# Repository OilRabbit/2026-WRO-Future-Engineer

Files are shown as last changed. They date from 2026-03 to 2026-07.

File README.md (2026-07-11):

# Welcome to the GitHub Repository of Team Evo1ution for 2026 WRO Future Engineering 

## Links

[About Our Team](#about-our-team)

[Documentation](https://github.com/OilRabbit/2026-WRO-Future-Engineer/blob/Gen-1.0/Documentation/2026WROFEReport.pdf)

[Vehicle photos](vehicle_photos)

[Practice Videos](https://github.com/OilRabbit/2026-WRO-Future-Engineer/tree/Gen-1.0/video/video.md)

[Our Code](https://github.com/OilRabbit/2026-WRO-Future-Engineer/tree/Gen-1.0/src)

[Wiring Diagram](https://github.com/OilRabbit/2026-WRO-Future-Engineer/blob/Gen-1.0/schemes/Kicad/gen1_wiringdiagram.pdf)

[Building Instructions](https://github.com/OilRabbit/2026-WRO-Future-Engineer/blob/Gen-1.0/Documentation/FE%20building%20instructions.pdf)

## About Our Team

Our team consists of seven alumni from Po Leung Kuk Tang Yuk Tien College, each of whom previously served as chairperson of the school’s Robotics Team or has a strong interest in robotics. Over years of competitions and training, we have built strong friendships and developed a shared commitment to robotics. Last year, our team participated in the WRO Singapore final and placed 28th. Although we want to achieve higher this year, two of our teammates cannot participate due to academic reasons. Thus, we have two new teammates this year, Harrison and Donald become part of our supporters this year.

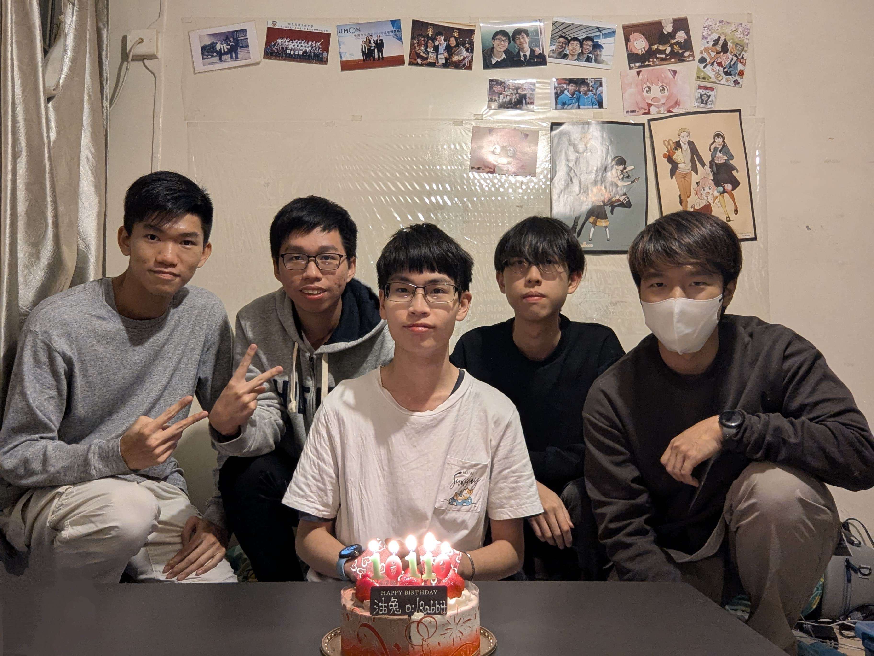
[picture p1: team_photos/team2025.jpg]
team_photo

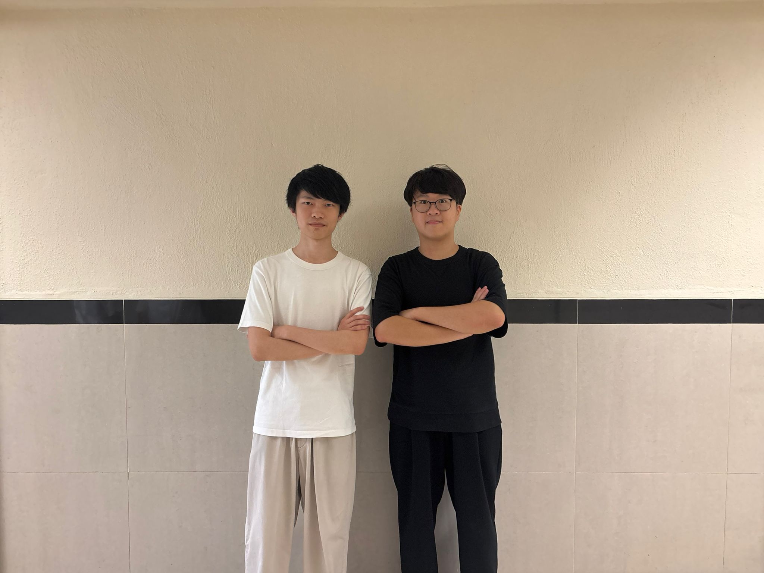
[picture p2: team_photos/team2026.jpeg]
team_photo

### Members' Introductions

#### Kyle Cheung (Participant) – Age 18
Kyle, a secondary school graduate, is responsible for program development in the PLKTYTC Robotics Team. He achieved first and second place in the 2023 and 2024 WRO Hong Kong RoboSports category. While preparing for the 2026 Robocon Hong Kong Contest, he draws on his strong competition background.

#### Marco Lam (Participant) – Age 19
Marco, an Enrichment Stream in Theoretical Physics student at The Chinese University of Hong Kong, is responsible for developing the main program, conducting module tests, and fine-tuning robot performance across diverse sce-narios. Although this is his first robotics competition since primary school, his strong foundation in programming — highlighted by achieving Honourable Mention in the Hong Kong Olympiad in Informatics (2022–
2023) — has proven valuable to the team. 

#### Rex Sin (Participant) – Age 20
Rex is studying Computer Science in Australia, but remains fully engaged in our team via video conferencing. He leads strategy design, debugging, and solution development, produces and uploads our YouTube videos, and co-ordinates this report. He began robotics at age 12 and won the U.S. Robot Parade world championship represent-ing Hong Kong, later earning numerous local competition awards.

#### Elwin Li (Coach) – Age 23
Elwin is an MPhil Physics student who previously coached the PLKTYTC Robotics Team and Physics Olympiad class. With expertise in physics, mathematics, and programming, he contributes to university research on gravita-tional waves. In our team, he directs meeting planning, goal setting, task assignment, sponsorship coordination, hardware procurement, and, most critically, programming strategy. Elwin also competed in the 2021 Robocon Hong Kong Contest and served as a judge for the 2024 WRO Hong Kong Future Engineer selection.

#### Donald Tong (Supporter) – Age 20
Donald, a Civil and Environmental Engineering student and PLKTYTC Robotics Team coach, develops core li-braries and functions, fine-tunes robot behavior, and conducts extensive operational tests, such as evaluating var-ied object placements. He and Rex Sin earned second place in the 2024 WRO Hong Kong Senior Robomission selection, and he previously placed second in the 2019 international Beach Rescue and Salvage Robot contests.

#### Harrison Tsang (Supporter) – Age 21
Studying Artificial Intelligence: Systems and Technologies, Harrison coaches the PLKTYTC Robotics Team and leads our robot construction and primary program development. While preparing concurrently for the 2025 Ro-bocon Hong Kong Contest, he brought experience as the 2021 WRO Hong Kong Senior RoboMission champion and multiple world-title winner in international robotics that year.

#### Harold Cheung (Supporter) – Age 24
Harold is a final-year Aeronautical and Aviation Engineering student and former PLKTYTC Robotics Team coach, specializing in mechanical design and robot structures. In our team, he delivers vehicle fundamentals training, oversees mechanical design, advises on sensor integration and strategy, and assists with component procure-ment. A motorsport enthusiast and amateur go-kart racer, Harold has competed alongside Elwin in robotics con-tests for over ten years, even leveraging insights from his personal kart to inform our robot’s design.

----

## Our design for the previous Copetition
During the previous Competition, we selected the ESP32 as controller and the BM50 brushless motor with an encoder for the drive. It offers additional stability, acting like a gyroscope while in operation, and features a built-in en-coder for precise power control. The smart car analyse the situation using a lot sensors, such as IMU, ToF sensors and camera(PixyCam2.1). The chassis was built with 3D printed frame and arcylic plates, assisted with LEGO components to connect the Ackermann system and wheels. 

previous_design

However, we found that the PixyCam2.1 feedback is not stable and it was prone to overexposure in the venue of competition. Moreover, the large amount of sensors made the vehicle bulky and increased the difficulty of connecting and repairing them.

----

## Our current design

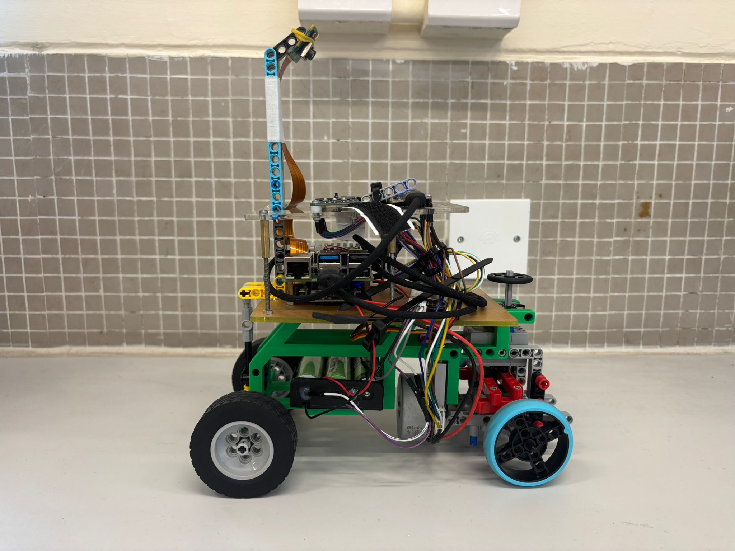
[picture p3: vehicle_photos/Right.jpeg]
right


This year, we are trying to measure the field with the camera only. This requires a reliable camera and a powerful processor to observe the field and analyse the graphical data. After researching other teams’ choices on camera, we decided to use the Raspberry Pi and its camera for this task due to the stability and high processing power.

Our new front-wheel drive system is also worth mentioning. We choose a front-wheel drive (FWD) drivetrain because it provides stable and predictable handling during auton-omous driving. The front wheels both steer and drive the vehicle, allowing them to pull the robot through corners and helping it maintain the intended trajectory. 

----

## Building instructions

----

## Our libraries for ESP32
### LED
Storing functions for changing the colour of the LED on the ESP32, which help indicate the state of the vehicle. Those functions are made just in case that we need them one day. They can be used for indicating the state of program while debugging.
### OC
Storing the main program for the challenge and the function for showing the run time.
### Serial
Storing functions for communicating with the Raspberry Pi. Those functions are not only responsible for sending and receiving message, but also translating command message for controlling electronic components.
### buttons
Storing functions that define the behaviour of buttons.
### calculation
Storing functions of math formulas that are frequently used. As the official library of motor and sensors might take values in different unit, some of those functions help us do the convertion.
### main
The program that initialise the threads and libraries.
### motor
Storing functions for controlling the BM50 motor, including that reads the value of its encoder. Those functions give us various ways to controll the motor, such as turn for certain degrees, and adding acceleration and deceleration.
### steering
Storing the functions for controlling the servo motor to do turning.
### tft
Storing the functions for printing messages on the monitor. Those functions are very useful in debugging, especially when we need to know some values while the program is running.
### timestamp
Storing a function to put into display thread for showing the time elapsed from the start of the smart car.
## Our libraries for Raspberry Pi
### camera_utils
Storing functions for analysing feedback from the camera, including those help recognise the track, the obstacles, and the parking lot.
### communications
Storing the functions that manage the communication with ESP32. The function for sending commands to ESP32 is frequently used for telling the state of the vehicle base on the camera feedback.

----

## What we learnt
* Slip angle optimisation is unnecessary for our small robot, the Ackermann effect is minimal, though we demonstrated a simple LEGO implementation regardless.
* A differential is essential: it significantly smooths turning at low speeds despite a slight reduction in straight‐line velocity.
* A shorter wheelbase enhances turning fluidity.
* A wider track during turns, greater spacing between front wheels than rear, improves cornering smooth-ness (we omitted this due to chassis‐width constraints).
* Lightweight wheels markedly increase top speed more than reducing overall vehicle mass.
* Smaller wheel diameters boost manoeuvrability.
* A low centre of mass enhances stability.
* An onboard gyro provides precise heading data and lap counting.
* Storing pillar colours in an array on the first detection enables faster reaction on subsequent passes.
* Reducing camera resolution (where feasible) increases frame rate and responsiveness.

----

## Conclusion
This is a really challenging project as this is our first time using those hardware and there are so many things need to learn for this. We enjoy the process of searching through the field we love and learning something new. We believe that what we learnt from this competition is more valuable than the result.

----

## Special thanks
Our sponsors:

| [Peach Creatice Production](https://www.peachcp.com/wp/) | [TURNED-E!](https://www.turned-e.com/) | [Scarlet Racing](https://www.facebook.com/scarlet.racing.hk/?locale=zh_HK) | Electronic Slash |
| --- | --- | --- | --- |
|||||

Also thank to our parents, coach and supporter for supporting us to explore the field we love.

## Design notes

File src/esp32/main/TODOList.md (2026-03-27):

## TODO List

### 1. ~~Rewrite `getLaser1Distloop` and `getLaser2Distloop` s.t. different method (plain, mean, mode) for getting the distance can be chosen when calling them~~

### 2. ~~Rewrite `showLaser1Dist` and `showLaser2Dist` s.t. different method (plain, mean, mode) for getting the distance can be chosen when calling them~~

### 3. ~~Rewrite all the functions in OC1.cpp~~

### 4. Write PID functions for steering using:
a. Laser b. IMU

### 5. Write a "UNUSED" macro

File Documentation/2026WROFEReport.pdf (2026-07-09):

# Team “Evo1ution” WRO Future Engineer Report

## Team name: Evo1ution Participants: Rex, Tak Chun Sin Marco, Lam Marco Kyle, Ka Hei Cheung Coach: Elwin, Ka Yau Li Supporter: Harold, Yat Long Cheung Donald, Kam Pan Tong Harrison, Kwok Ho Tsang

## Sponsors:

# Table of Contents

# About Us

We are Team Evo1ution. The team name is derived from the word “Evolution,” reflecting our commitment to continuous improvement and our determination to strive for the best. This spirit has guided us since our time in the robotics team during secondary school. We intentionally replaced the letter “l” with the number “1” to symbolise our ambition to achieve first place in the competition.

Our team consists of seven alumni from Po Leung Kuk Tang Yuk Tien College, each of whom previously served as chairperson of the school robotics team and shares a strong interest in robotics. Through years of competitions and training, we have built strong friendships and developed a shared commitment to robotics.

Last year, we participated in the WRO Future Engineers category in both the Hong Kong Regional Round and the International Final in Singapore. We achieved the Regional Championship in Hong Kong and placed 28th in the International Final. This year, we aim to build on that experience and achieve an even better result by making significant improvements to our robot. Unfortunately, two of our previous teammates, Donald and Harrison, are unable to participate due to academic commitments. Therefore, we recruited two new teammates, Kyle and Marco, to join us as we continue working towards victory.

# Members' Introductions and Thoughts

Kyle Cheung (Participant) – Age 18

Kyle, a secondary school graduate, is responsible for program development in the PLKTYTC Robotics Team. He achieved first and second place in the 2023 and 2024 WRO Hong Kong RoboSports category. While preparing for the 2026 Robocon Hong Kong Contest, he draws on his strong competition background.

“It is a wonderful change from recognising and chasing the table tennis ball to dodging the pillars. As a rookie of this selection, I learnt to manipulate Raspberry Pi and Esp 32 for the advanced mission, in addition to a camera. The adventure of creating an integrated algorithm is both a torture and a boon at the same time: I mastered the skill of camera data acquisition, but the tuning part took me days and nights.”

Marco Lam (Participant) – Age 19

Marco, an Enrichment Stream in Theoretical Physics student at The Chinese University of Hong Kong, is responsible for developing the main program, conducting module tests, and fine-tuning robot performance across diverse scenarios. Although this is his first robotics competition since primary school, his strong foundation in programming — highlighted by achieving Honourable Mention in the Hong Kong Olympiad in Informatics (2022–
2023) — has proven valuable to the team.

“Initially, I expected the Future Engineer challenges to be relatively straightforward. However, I quickly encountered numerous bugs in the main program that required extensive debugging. Through systematically identifying and resolving these issues, I discovered how interesting and rewarding this kind of
challenge can be. These experiences have sharpened my problem-solving

skills and deepened my appreciation for iterative testing and robust system development.”

Rex Sin (Participant) – Age 20

Rex is currently studying Computer Science in Australia but remains fully engaged with the team through video conferencing. He leads strategy design, debugging, and solution development, produces and uploads our YouTube videos, and coordinates the preparation of this report. Having begun his robotics journey at the age of 12, he won the U.S. Robot Parade world championship while representing Hong Kong and has since earned numerous awards in local competitions.

“From the experience of participating in this competition last year, I learnt that it demands not only an optimised mechanical design for navigating obstacles but also a significant programming effort. I am grateful to my teammates for involving me despite my being overseas. My primary contribution has been to ensure our documentation is

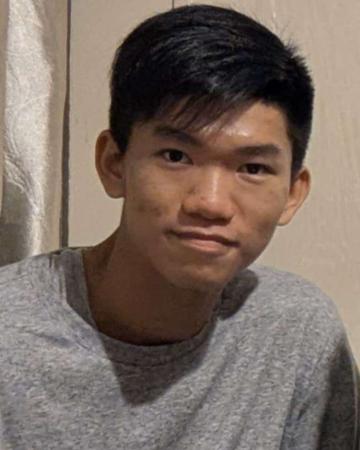
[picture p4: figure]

as polished as possible, so the team can focus on fine-tuning the robot. Researching mechanical features to justify each design choice has deepened my understanding, as I consulted multiple sources and carefully edited this report.”

Elwin Li (Coach) – Age 23

Elwin is an MPhil student in Physics who previously coached the PLKTYTC Robotics Team and the Physics Olympiad class. With expertise in physics, mathematics, and programming, he contributes to university research on gravitational waves. Within our team, he is responsible for meeting planning, goal setting, task allocation, sponsorship coordination, hardware procurement, and, most importantly, programming strategy. Elwin also competed in the 2021 Robocon Hong Kong Contest and served as a judge for the 2024 WRO Hong Kong Future Engineers selection. In addition, he led our team in participating in the 2025 WRO Future Engineers Hong Kong Regional Round and the International Final in Singapore.

“As a former student and coach of Po Leung Kuk Tang Yuk Tien College, I am privileged to mentor this talented new generation through a streamlined yet exceptionally

demanding competition. The Open Challenge strengthens core navigation skills, while the Obstacle Challenge requires advanced image processing, adaptability, and the ability to respond to constantly changing conditions. I greatly admire my team’s unwavering dedication. They have invested countless hours in mechanical analysis, control algorithm refinement, and comprehensive subsystem testing. Their intellectual curiosity and collaborative spirit reflect the highest standards of our robotics programme, and I am proud to lead such a capable and committed group. Beyond robotics, we are also close friends who regularly spend time together, play games, and enjoy hotpot gatherings at my home. Their camaraderie brings laughter, warmth, and genuine friendship to every project. I cherish this team not only for their technical excellence, but also for the strong bonds we share.”

Harold Cheung (Mechanical Supporter) – Age 24

Having graduated with a degree in Aeronautical and Aviation Engineering, Harold is now an educator teaching Design and Technology (D&T) and Computer Literacy at Shun Tak Fraternal Association Cheng Yu Tung Secondary School, where he also manages robotics clubs and develops STEAM curricula. Serving as the team's Technical Supporter, he provides critical guidance on mechanical design. This year, he spearheaded the development of the robot's new Front-Wheel Drive (FWD) system and took charge of 3D printing for rapid prototyping. As a motorsport enthusiast and co-editor of STEM textbooks, Harold excels at drawing inspiration from real-world mechanics and translating those practical physical principles into innovative competitive robotics design.

“I am thrilled to compete once again alongside my juniors. Although I have worked with WRO Hong Kong, my experience has been primarily in RoboMission, so I was not initially

familiar with the Future Engineer format. After studying the rules, I realised that we would need a system as advanced as a Tesla. Drawing on my go-kart racing background and many years of local WRO competition, I guided the team in self-driving car design and used this opportunity to teach my juniors key automotive principles and mechanical structures. Even in a supporting role, I have greatly enjoyed this process and hope that my contributions will enhance our overall performance.”

Donald Tong (Supporter) – Age 20

Donald, a Civil and Environmental Engineering student and coach of the PLKTYTC Robotics Team, is responsible for developing core libraries and functions, fine-tuning robot behaviour, and conducting extensive operational tests, including evaluating performance under varied object placements. Together with his teammate Rex Sin, he achieved second place in the 2024 WRO Hong Kong Senior RoboMission selection. He also previously secured second place in the 2019 international Beach Rescue and Salvage Robot competitions.

“This is my second time playing future engineering, but I changed my role to supporter this time. By learning from the failure of last year, I can share my experiences on what we can avoid doing to the participants when they participate in the competition. Also, as a supporter, I learned more skills to provide ideas and instructions on drawing CADs and laser cuts. These experiences must help me gain a lot.”

Harrison Tsang (Supporter) – Age 21

Currently studying Artificial Intelligence: Systems and Technologies, Harrison coaches the PLKTYTC Robotics Team and leads our robot construction and primary program development. While simultaneously preparing for the 2025 Robocon Hong Kong Contest, he draws on his experience as the 2021 WRO Hong Kong Senior RoboMission champion and as a multiple world-title winner in international robotics that same year.

“Having competed as a participant in the past, I would say the Future Engineer challenges do not mirror our previous RoboMission experience. Stepping into a supporter role this time gave me a fresh perspective on the unpredictable nature of sensor and camera performance. For instance, when the team's PiCam misidentified walls, floors, and computers as green during testing, I was able to draw on my past experience to guide them through the troubleshooting process. Helping the team master camera data

acquisition techniques from the sidelines gave me a much deeper appreciation for what it means to be an effective, supportive teammate.”

# 1. Choice of Electromechanical Components

Controller and Sensors

Last year, during the International Final in Singapore, we selected the ESP32-S3 development kit as the main and sole controller for our robot. The ESP32-S3 features a dual-core processor, allowing it to process data from different sensors and the camera while simultaneously controlling the motors. By incorporating FreeRTOS, a real-time operating system, we were able to implement multitasking, enabling the ESP32-S3 to communicate with multiple connected components at the same time. This made it effective for executing several tasks concurrently.

However, we found that the processing power of the ESP32-S3 was insufficient for handling the large amount of data from the camera while maintaining stable communication with other electronic components. Therefore, we decided to use a more powerful controller capable of processing raw camera data more efficiently.

As a result, we have chosen the Raspberry Pi 5 as the main controller for our robot this year. Despite its compact size, the Raspberry Pi 5 provides significantly stronger processing power, supports a dedicated operating system, and is compatible with the Raspberry Pi Camera Module 3 Wide. Since the Pixy 2.1 camera module was not stable enough for us to achieve consistent performance during the Obstacle Challenge and was easily affected by slight changes in ambient lighting, we decided to use the Raspberry Pi Camera Module 3 Wide as our camera module this year. Following the principle that “simplicity is best”, we also decided not to include any distance sensors or inertial measurement units (IMUs). Instead, we will rely solely on the camera module to complete the challenges.

Although the Raspberry Pi 5 is used as the main controller for image processing and decision-making, we decided to keep the ESP32-S3 as a dedicated motor controller for the driving and steering systems. Compared with the Raspberry Pi 5, the ESP32-S3 is more suitable for low-level motor control because it can generate stable PWM signals and communicate directly with motor drivers and servo motors with lower latency.

This separation also allows the Raspberry Pi 5 and ESP32-S3 to focus on different tasks. The Raspberry Pi 5 handles camera input, image processing, and high-level navigation decisions, while the ESP32-S3 receives control commands and translates them into precise motor actions. This improves the overall stability of the system and reduces the processing load on the Raspberry Pi 5.

In addition, the ESP32-S3 is easier to program for direct hardware control, especially for tasks such as speed control, steering control, and real-time response to motor commands. By using the ESP32-S3 as a dedicated motor controller, we can achieve a more reliable and organised control architecture for the robot.

Driving system (Motor)

For the driving system, we selected the BM50 brushless motor with an integrated encoder. Although the motor is compact in size, it provides a strong balance of high rotational speed, sufficient torque, stable operation, and precise controllability, making it highly suitable for the WRO Future Engineers challenges.

One of the main reasons we chose this motor is its built-in encoder, which allows us to monitor the motor’s rotation accurately in real time. This enables more precise speed control and helps the robot maintain consistent movement during both the Open Challenge and the Obstacle Challenge. Since the robot needs to travel smoothly, adjust its speed when turning, and respond reliably to visual input from the camera, accurate motor feedback is essential for stable autonomous driving. The BM50 motor only requires a 12V power supply, making it compatible with our robot’s electrical system without requiring a complex power setup. It has a maximum rotational speed of (4450 ±
445) RPM, a stall torque of 60mN·m, and a maximum torque of 423mN·m. This gives us a wide operating range, allowing the robot to move quickly on straight sections while still having enough torque to handle acceleration, turning, and small disturbances during the run.

Another important advantage of this motor is its built-in safety mechanism. If the motor stalls for two seconds due to external forces, it automatically stops to prevent damage. This is especially useful in the WRO environment, where the robot may accidentally hit walls, obstacles, or track boundaries during practices. This protection improves the reliability of our system and reduces the risk of damaging the motor during repeated trial runs.

Therefore, the BM50 brushless motor provides the speed, torque, feedback control, and safety features required for a stable and responsive autonomous robot. Its compact form factor also allows us to design a lighter and more space-efficient driving system, which supports our goal of building a simple, reliable, and high-performance robot for this year’s competition.

Steering

For the steering system, we selected the compact CZ356 servo motor. One of the main reasons for choosing this servo is its small size and LEGO-compatible design, which allow us to mount it directly onto the robot using simple LEGO parts. This makes the steering mechanism easier to assemble, adjust, and maintain during testing.

Since the robot needs to perform accurate and responsive steering in both the Open Challenge and the Obstacle Challenge, a compact servo motor is advantageous because it reduces the overall size and weight of the front steering structure. Its LEGO compatibility also helps us design a cleaner and more modular mechanism, allowing the servo to be securely fixed without requiring complicated custom-made parts.

Debug Display

We selected the Waveshare 1.3” IPS LCD Display HAT with a 240×240 resolution as the display module for the robot. It allows us to show important information, system status, and debugging messages during testing and practice sessions. By displaying real-time data directly on the robot, we can monitor its operation more conveniently without always needing to connect it to an external computer.

The display module also includes three push buttons, which provide a simple way to control the robot during testing. For example, we can start or stop the program with a single button press, making the debugging process faster and more efficient. This is especially useful during repeated trial runs, as it allows us to quickly restart or adjust the robot without changing the code or reconnecting external devices.

Powering Unit

For the power system, we use three enhanced 18650 rechargeable batteries with a higher capacity than standard 18650 cells. Compared with typical 1800mAh batteries, our selected 3200mAh cells provide a longer operating time and help ensure a more stable power supply during practice sessions and throughout the competition day.

Using three 18650 cells allows us to provide approximately 12V to the main power system of the robot, which is suitable for powering the driving motor and other electronic components. However, the Raspberry Pi 5 requires a stable 5V input. Therefore, we use a YB-MPP01-V1.0 power supply expansion board for the Raspberry Pi 5 to step down the voltage from the battery pack to a regulated 5V output. This ensures that the Raspberry Pi 5 can operate reliably without being affected by voltage fluctuations from the main battery system.

A stable power system is important because sudden voltage drops may cause the Raspberry Pi 5 to restart, interrupt the camera processing, or affect communication with the ESP32-S3. By using high-capacity batteries together with a dedicated voltage regulation board, we can improve the reliability of the robot during long testing periods and competition runs.

Further details and specifications of our selected electronic components are provided in Section 3.

# 2. Mobility Management

## 2.1. Overview

The mobility and specialised characteristics of a kart make it an ideal prototype for the WRO Future Engineers competition missions. A kart has a simple yet robust chassis, as well as a straightforward steering system, making it a suitable reference model for our robot design. Our supporter, Mr Harold Cheung, who is an amateur go-kart racer, provided detailed photographs of his kart for our reference.

Mr Cheung and our coach, Mr Elwin Li, also invited their friend, Mr Lewis Wong, to explain how a car operates and which factors influence its performance, stability, and handling. Mr Wong is currently a mechanical engineer in Touring Car Racing (TCR) and has extensive experience in race car setup. His explanation helped us better understand the relationship between wheel alignment, steering response, weight distribution, and vehicle stability. Further details are provided in the appendix, “How Wheels Affect a Car’s Performance?”

In addition, Rex and Elwin evaluated an electric go-kart in Australia to compare its performance with that of a conventional petrol-powered model. This comparison allowed us to better understand the differences in acceleration, power delivery, handling, and overall driving behaviour between electric and conventional kart systems. The key mobility-enhancing features we investigated are as follows:

- Mechanical differential
- Ackermann Steering
- Chassis Design:

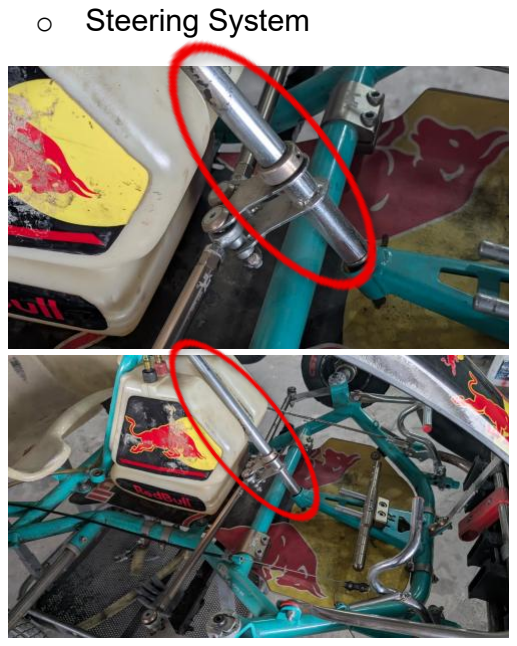
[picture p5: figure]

- | Design Overview | o | Steering System

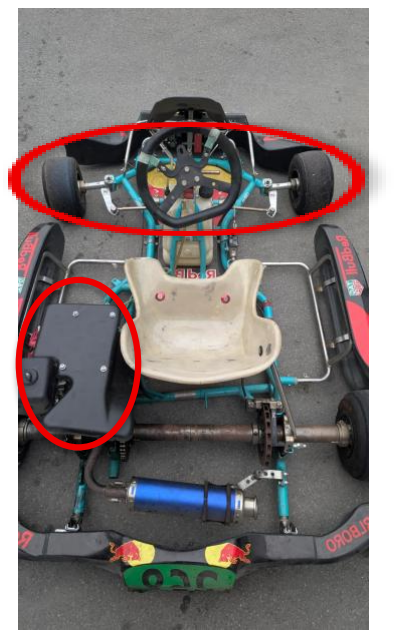
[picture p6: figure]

These design characteristics were applied to the smart car last year and evaluated to determine their effectiveness in the WRO Future Engineers missions. Although the go-kart-inspired rear-wheel-drive (RWD) design last year provided excellent straight-line speed, we observed clear limitations during sharp cornering, particularly when entering and exiting the parking area.

Our reference of Ackermann steering system and the motor (the black box on the left of the seat) that is placed in the middle of the kart.

The axle that controls the Ackermann steering system.

Building on our previous prototype, our team conducted a comprehensive review of the robot’s mobility system. Through testing, we identified two major mechanical issues: understeering during tight turns and structural weakness at the front axle. These problems compromised the robot's turning stability and reduced its reliability during more demanding sections of the challenge.

To address these limitations, we designed a completely state-of-the-art front-wheel-drive (FWD) architecture for the Future Engineers challenges this year. This new system integrates our proven differential mechanism and Ackermann steering geometry into the front driving axle. By moving the driving force to the front wheels, we aim to improve traction, steering response, and control during sharp turns, especially in complex manoeuvres such as navigating around obstacles and entering the parking area.

## 2.2. Mechanical Differential

Although most vehicles rely on a differential to enable smooth cornering, conventional and electric go-karts typically do not incorporate one. To evaluate the effectiveness of a differential in our robot, we first recorded the differential mechanism of our smart car in slow motion to verify that it functioned correctly. We then measured the right-angle turning radius and turning time with and without the differential installed. Our results showed that incorporating the differential reduced the turning radius by approximately 3cm.

Due to size constraints, we adopted a 20:28 gear ratio from the driving motor to the differential (Fig. 1), which reduced the top speed of the robot by approximately 30%. As shown in Fig. 2, the plotted trajectories, where the dotted lines represent the setup without a differential and the solid lines represent the setup with a differential, demonstrate the effect of wheel-speed variation during turning. Under equal driving torque, the inner wheel must travel a shorter path than the outer wheel. Without a differential, both wheels are forced to rotate at the same speed, causing wheel slip and reducing turning efficiency. By allowing the inner and outer wheels to rotate at different speeds, the differential prevents inner-wheel spin and enables smoother, more stable, and more efficient turning. In addition, the torque is significantly increased by 40%, which enhances the grip when operating at high speed. Table I shows a detailed comparison for different setups.

After comparing the pros and cons when including or excluding a differential, we decided to retain it in the design this year. Since the BM50 motor uses a D-shaft, we created a CAD model and ordered a CNC-machined metallic D-shaft-to-LEGO-axle adaptor to connect the motor reliably with LEGO-compatible components. This adaptor allows us to combine the higher performance of the BM50 motor with the modularity and flexibility of LEGO-based mechanical construction.

Tests \ Setups | W/o differential | 20:28 differential | % difference
Top speed | 4450RPM | 3112RPM | -30.0%
Turning radius | 35cm | 32cm | -8.6%
Toque | 423mN·m | 592mN·m | +40%
Turning performance | Understeer | Smooth | ---
Low-speed control | Worse | Better | ---
Motor load during turning | Higher | Lower (reduced resistance) | ---
Mechanical complexity | Lower | Higher | ---
Gear backlash | No | Yes | ---
Weight | Lower | Higher | ---
Note: Red: Worse, Green: Better

Table I. Performance comparison between configurations with and without a mechanical differential, based on experimental testing and measurements. Green cells indicate the configuration with better performance for a given criterion, while red cells indicate comparatively poorer performance.

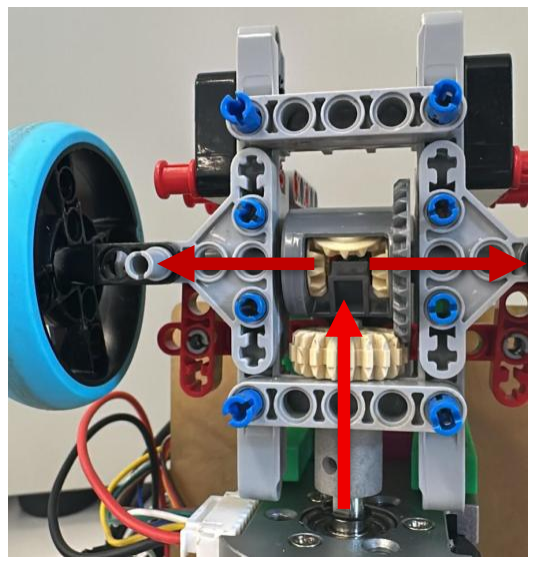
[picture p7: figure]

## 2.3. Ackermann Steering

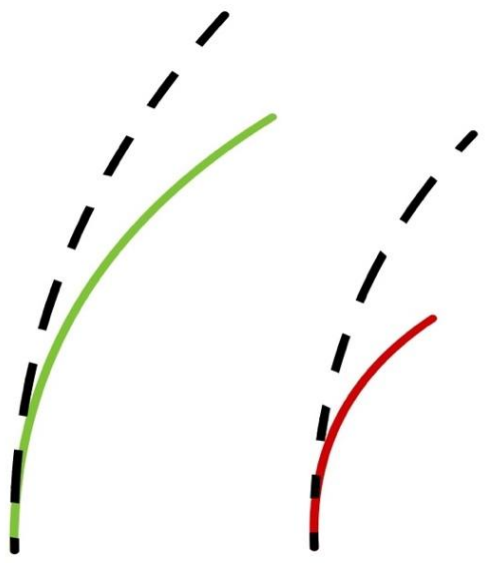
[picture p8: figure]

Ackermann steering geometry improves turning performance by ensuring that the inner and outer front wheels are aligned toward a common instantaneous centre of rotation during low-speed manoeuvres. While go-karts typically use steel tubing and adjustable linkages to achieve precise steering geometry, our LEGO-based Ackermann steering system uses a simplified linkage design that still provides measurable improvements in cornering performance, as illustrated in Fig. 4.

In an Ackermann steering system, the inner wheel turns at a sharper angle than the outer wheel. This allows all four wheels to follow concentric paths around a common centre of rotation during a turn. If both front wheels were set to the same steering angle, they would resist each other’s motion, increasing rolling resistance, tyre slip, and energy loss. By combining the Ackermann steering mechanism with our new FWD differential setup, we were able to minimise sliding and improve turning efficiency.

Our Ackermann Steering | Ideal Ackermann Steering

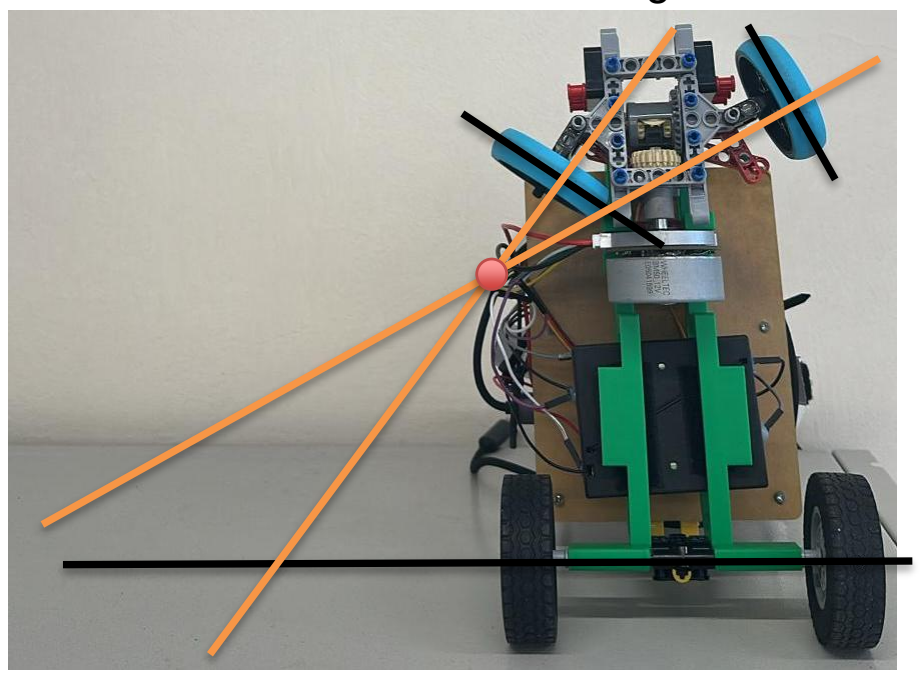
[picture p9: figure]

Fig. 4. Ackermann steering applied in our smart car.

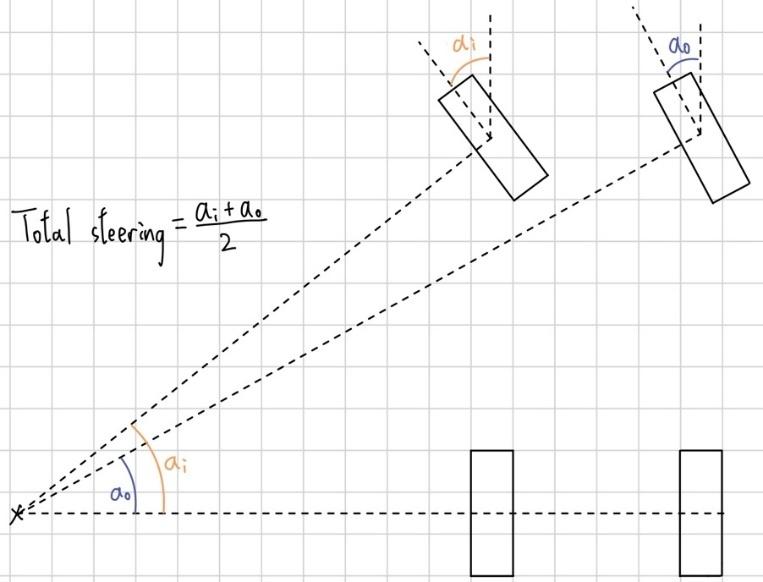
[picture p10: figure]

Fig. 5. A sketch showing an ideal Ackermann steering and the final steering angle with this system.

Fig. 1. Mechanical differential of the robot | Fig. 3. CAD model of the D- shaft-to-LEGO-axle
Fig. 2. Path differences between the inner and outer wheel sets with and without differential.

## 2.4. Chassis Design

A shorter wheelbase improves manoeuvrability and agility by allowing the vehicle to complete tighter turns. Figure 7 compares the turning radii of long- and short-wheelbase configurations, calculated using the maximum inside-wheel steering angle under ideal Ackermann geometry. As shown in the figure, the shorter wheelbase produces a noticeably smaller turning radius.

To observe this effect in real vehicles, we visited an industrial area and compared the turning behaviour of different heavy vehicles. We observed that a standalone Scania tractor unit had a relatively small turning radius, allowing the driver to complete a left turn directly by steering left. In contrast, a Scania tractor hauling a container required a much larger turning space. The driver first steered slightly to the right to create enough clearance before turning left. Although the tractor units were essentially the same, the attached container increased the overall vehicle length and swept path, making tight cornering more difficult in narrow spaces.

Guided by this observation, we reduced the wheelbase of our robot to improve agility and cornering response. At the same time, we placed the heavier components in the lower part of the chassis to maintain a low centre of gravity and improve stability during turns.

Although shortening the chassis can increase the risk of oversteering, our FWD design helps reduce this issue by placing both the driving and steering functions on the same pair of front wheels. Since the front wheels actively pull the robot in the intended direction, the robot can maintain better directional control during turns. This reduces the tendency of the rear section to swing outward, especially when cornering at higher speeds or making sharp manoeuvres.

In addition, the compact chassis improves agility, while the FWD layout helps preserve stability. By combining a shorter wheelbase with careful weight distribution and front-wheel traction, we were able to achieve tighter turns without significantly compromising control.

During a turn, the inside wheel follows a shorter arc than the outside wheel. If both front wheels share the same steering angle, they cannot follow concentric paths, resulting in tyre slip and increased rolling resistance. Ackermann steering addresses this issue by turning the inside wheel at a sharper angle than the outside wheel, aligning all wheels toward a common centre of rotation. This geometry minimises sliding, reduces resistance, and enables smoother cornering. In our tests, implementing Ackermann steering reduced the turning radius of our smart car by approximately 5%.

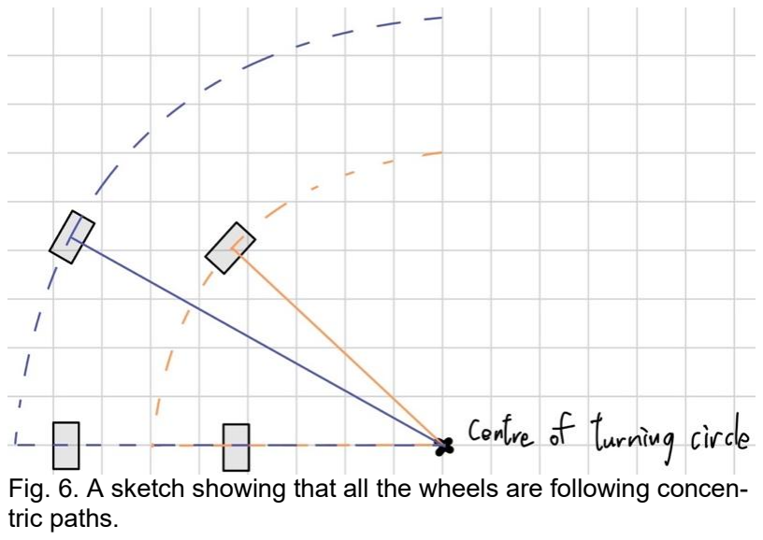
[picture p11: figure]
tric paths.

Fig. 6. A sketch showing that all the wheels are following concen-

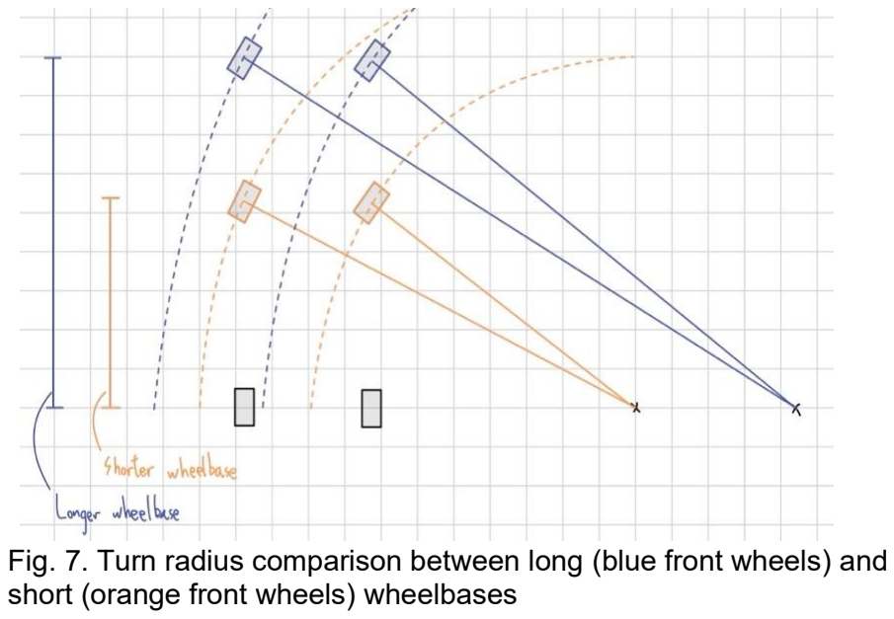
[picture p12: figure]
short (orange front wheels) wheelbases

Fig. 7. Turn radius comparison between long (blue front wheels) and

Based on our previous experience, we realised that relying heavily on LEGO elements limited the flexibility of our mechanical design, especially when compared with a fully custom 3D-printed chassis. Although LEGO components are convenient for rapid prototyping and adjustment, they also impose constraints on structural layout, component placement, and overall compactness.

To address these limitations, we first rebuilt the main frame using acrylic plates. This improved the rigidity of the chassis and allowed us to arrange the electronic and mechanical components more flexibly. The acrylic frame also provided a more stable platform for testing different drivetrain and steering configurations.

After further evaluation, we designed a 3D-printed main frame to reduce the overall size of the robot and improve integration between different components. This custom chassis allowed us to create a more compact, lightweight, and purpose-built structure, further enhancing its mobility, stability, and overall performance.

## 2.4.1 Centre of Mass Consideration

## Benefits of a low centre of mass design

### Reduced Rollover Risk:

During cornering, lateral acceleration generates an outward rolling moment that is proportional to the height of the centre of mass. Lowering the centre of mass reduces this rolling moment and improves the vehicle’s resistance to rollover.

### Impact on Inertia:

A lower centre of mass helps reduce body roll during steering and directional changes. This allows the robot to respond more predictably to steering inputs, especially when making sharp turns or quick corrections.

### Increased Stability:

Lowering the center of mass improves overall stability and reduces the robot’s sensitivity to external disturbances, such as uneven surfaces, sudden acceleration, or minor collisions with track boundaries.

### Better Cornering:

During cornering, weight shifts toward the outer wheels. A lower centre of mass reduces this weight transfer, allowing the wheels to maintain more consistent contact with the ground. This improves grip and enables faster, smoother, and more controlled turns.

In summary, a low center of mass is essential for stability, safety, and responsive handling. Therefore, we arranged the components of our smart car as close to the chassis as possible and removed nonessential parts. The heaviest components, the battery box and the driving motor, are mounted at chassis level, while only the camera is positioned above the main board. This layout helps reduce rollover risk during high-speed turning, improve cornering stability, and maintain a compact overall structure.

## 2.4.2 Weight Control

Minimising the mass of the smart car is critical for maximising speed. Proved by the following formula,

KE =

1
2

mv

2

a lower mass m yields a higher velocity v for a given energy input KE. Wheel mass is especially influential because it directly affects rotational inertia and acceleration. We, therefore, selected the lightest available LEGO wheels and rigorously limited component count, constructing the Ackermann linkage with the fewest pieces and installing only essential modules.

## 2.5. The Front-Wheel Drive (FWD)

The transition from rear-wheel drive (RWD) to front-wheel drive (FWD) was a strategic engineering decision aimed at improving cornering stability and manoeuvrability. A detailed comparison of our experimental results for the RWD and FWD configurations is presented in Table II.

## 2.5.1 Decision and Benefits using FWD

In our mechanical setup, which uses plastic and rubber components on a competition mat, the RWD configuration tended to push the robot through turns. This made sharp cornering more difficult and increased the risk of understeering or wheel slip. After comparing the advantages and disadvantages of both drivetrain layouts, we decided to implement FWD in our robot this year, despite its greater mechanical complexity compared with an RWD design.

By adopting an FWD system, the front wheels actively pull the robot along the intended trajectory. Since the same pair of wheels is responsible for both steering and driving, the driving force helps guide the robot through the turn rather than resisting the steering motion. This allows the robot to achieve larger effective steering angles while maintaining better traction and directional control.

During testing, this integrated front-end system successfully reduced the turning radius to 25 cm and achieved a consistent cornering time of approximately 1 second. These results demonstrate that the new FWD architecture provides significantly better cornering performance than our previous RWD design.

Tests \ Setups | RWD | FWD
Stability | Understeer during sharp turns | Stable when entering corners
Cornering | Push the car wide when too much power | Easier to control, especially at low speeds
Traction | Poorer when rear traction is lost | Higher as weight shifts forward
Acceleration | Better as weight shifts to the rear | Worse as weight shifts backwards, losing front-wheel traction
Mechanical design | Simpler | More complex
Straight-line speed | Faster but less stable | Stable but slightly slower
Parking | Fast but less precise | Easier to control

Table II. Experimental performance comparison of the rear-wheel-drive and front-wheel-drive configurations. For each criterion, green cells indicate the better-performing configuration, while red cells indicate comparatively poorer performance.

## 2.5.2 Kinematic Analysis: Overcoming Understeer

To understand the necessity of shifting from rear-wheel drive (RWD) to front-wheel drive (FWD), it is important to analyse the underlying vehicle dynamics, particularly the traction limits and force directions acting on the robot during cornering.

In real-world automotive engineering, FWD vehicles are often more prone to understeer because the front tyres must share their available grip between steering and acceleration. However, our testing showed that the behaviour of our LEGO-based robot was different from that of a full-scale vehicle. The friction coefficient between our wheels and the competition mat is much lower than that of real tyres on asphalt, which significantly changes the balance between driving force, lateral grip, and steering response.

In our previous RWD setup, the rear wheels generated the forward driving force while the front wheels were responsible only for steering. When the front wheels were turned at a large angle, they did not have enough lateral grip to redirect the chassis effectively. As a result, the rear wheels continued to push the robot forward, while the angled front wheels resisted the motion instead of guiding the robot through the turn. This conflict between the rear driving force and the front steering direction caused severe understeer. It also created large lateral forces on the steering knuckles, which contributed to structural failures where the front wheels detached during testing.

The FWD architecture reduces this problem by aligning the driving force more closely with the steering direction. Since the front wheels are responsible for both driving and steering, the force pulling the chassis is directed along the intended path of the turn. Meanwhile, the rear wheels act mainly as free-rolling trailing wheels, reducing the opposing force that previously pushed the robot straight ahead. This improved force alignment reduces understeer, lowers lateral stress on the steering components, and provides more stable cornering performance.

## 2.6. Independent Rear Stub Axle Assembly

To complement our new front-wheel-drive (FWD) architecture, we completely redesigned the rear wheel assembly. Instead of using a continuous solid axle or adding a rear differential, we implemented an independent rear stub axle system.

Mechanical Integration:
The rear wheels are mounted on two separate, non-driven stub axles, also known as dead axles. These short independent shafts are inserted directly into a custom-designed 3D-printed support structure, which is rigidly secured to the main chassis. Unlike a conventional solid-axle setup, there is no mechanical linkage or continuous shaft connecting the left and right rear wheels.

Kinematic Advantages:
This design was selected to match the kinematic requirements of our FWD system. Since the front axle is responsible for both propulsion and steering, the rear wheels only function as load-bearing, free-rolling trailing wheels.

During a turning manoeuvre, the outer rear wheel follows a longer arc than the inner rear wheel and therefore needs to rotate at a higher speed. If a solid rear axle were used, both rear wheels would be forced to rotate at the same speed. This would cause one wheel to slip or drag along the competition mat, increasing rolling resistance and reducing cornering efficiency.

By using independent stub axles, the left and right rear wheels are mechanically decoupled. This allows them to rotate at different speeds naturally during cornering, passively accommodating the required wheel-speed difference. As a result, we can avoid using a complex and bulky rear differential while reducing overall weight, mechanical friction, and energy loss. This design supports smoother and more efficient cornering, which is especially important for sharp turns and parking manoeuvres in the WRO Future Engineers missions.

Fig. 8. Independent Rear Stub Axle Assembly

# 3. Power and Sense Management

## 3.1. Power consumption of electrical components

Table III shows the power requirements for all the electronic components of the robot.

| Current (A) | Voltage (V) | Power (W)
ESP32-S3 | ~ 0.06 | 5 | ~ 0.3
BM50 motor with encoder | < 0.65 | 12 | < 7.8
Raspberry Pi 5 | < 3 | 5 | ~ 15
Pi Camera module 3 wide | ~ 0.2 | 3.3 | ~ 0.65
LCD HAT | ~ 0.04 | 3.3 | ~ 0.132
CZ356 | ~ 0.55 | 5 | < 2.75

## 3.2. Voltage Converter (YB-MPP01-V1.0)

The YB-MPP01-V1.0 is a buck converter designed for the Raspberry Pi 5. Its function is to step down the input voltage from the main battery source to a lower and stable output voltage suitable for the Raspberry Pi.

Since the robot must operate independently during the challenges, it is not possible to power the Raspberry Pi using a 5 V power adapter connected to a wall socket.
Therefore, a voltage converter is required to convert the battery voltage into a stable 5 V supply for the Raspberry Pi. By using the YB-MPP01-V1.0 power supply

expansion board, we can ensure that the Raspberry Pi 5 receives a reliable power input while the robot remains fully mobile during testing and competition runs. The minimum efficiency of this board is approximately 80%.

## 3.3. Power Source (Enhanced 18650 batteries)

Drawing on our previous WRO RoboMission experience, we recognised that robot performance can be sensitive to battery condition and voltage stability. Therefore, we selected batteries with a higher capacity and a more stable voltage output under load than standard zinc–carbon batteries.

18650 alkaline zinc battery is the best choice for our robot. Using the data from Table III, we can estimate the capacity of electricity required for operating one hour at maximum power:

The total maximum power required from the power source is given by

15 + 2.75 + 0.132 = 22.3525 W.

Since the minimum efficiency of the YB-MPP01-V1.0 buck converter board is 80%, the power required directly from the power source, including the BM50 motor, which is directly connected to the power source, is

22.3525
80%

+ 7.8 = 30.1525 W.

Assume the maximum output voltage of the power source is 12V; the capacity of the power source required for operating one hour at maximum power is

30.1525
12
- 1 · 1000 = 2512.7 mAh.

Compared with our original 1500mAh batteries, each of the enhanced 3200 mAh cells provide an additional 1700mAh of capacity. This allows the robot to operate for longer periods between charges, giving us more continuous testing time during practice and improving reliability throughout the competition day.

Table III. Summary of the power requirements for the electronic components used in the robot.

Based on our calculated power requirement, the robot requires approximately 2512.7 mAh of capacity for operation. Since the three 18650 batteries are connected in series, the total voltage increases to approximately 11.1 V nominal, or 12.6 V when fully charged, while the battery-pack capacity remains 3200 mAh. Therefore, the selected battery pack provides sufficient capacity for the required operating time, with an additional safety margin of approximately 687.3 mAh.

Figure 9 compares the discharge curves of the two battery types. The alkaline zinc battery shows a noticeably flatter voltage profile, indicating smaller voltage fluctuations over time. Based on this comparison, we chose rechargeable 18650 alkaline zinc batteries instead of conventional zinc–carbon cells because they provide better voltage stability and are more environmentally friendly due to their reusability.

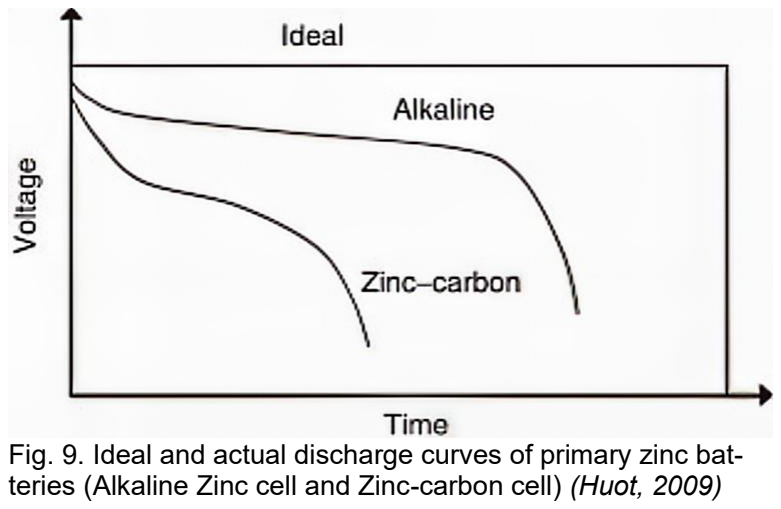
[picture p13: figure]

## 3.4. Camera (Pi Camera Module 3 Wide)

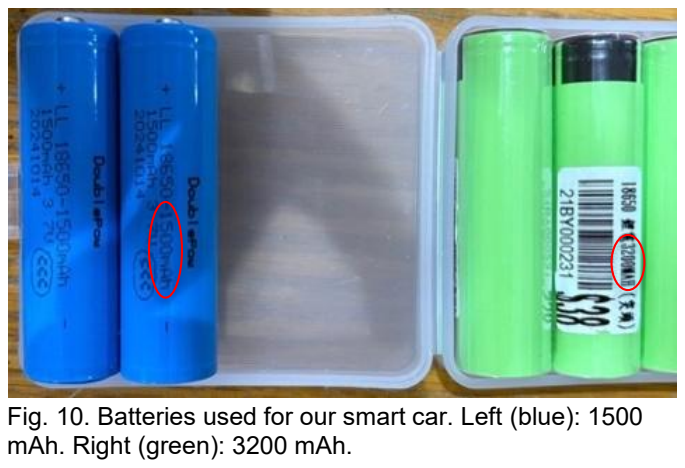
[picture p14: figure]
mAh. Right (green): 3200 mAh.

Before construction, we researched competitor strategies and identified two main obstacle-detection methods: close-range colour sensing and camera-based vision. A camera-based system allows the robot to detect multiple obstacles simultaneously and recognise the track layout from a greater distance. This enables earlier decision-making and faster responses during both the Open Challenge and the Obstacle Challenge. Therefore, we adopted a vision-based approach for the robot this year.

Previously, we used the Pixy 2.1 camera module. However, through testing, we found that its performance was not sufficiently stable across different environments, especially when lighting conditions changed. As a result, we switched to the Raspberry Pi Camera Module 3 Wide. This camera can capture images at up to 12 megapixels and provides a wide field of view, allowing the robot to detect obstacles, track boundaries, and road features at greater distances with improved accuracy and consistency.

## 3.5. Motor with encoder (BM50 with encoder)

While preparing for the previous competition, we learned about the BATTLEACE robot competition, where participating robots use compact motors capable of delivering high speed and high power output. This inspired us to search for a fast and powerful motor with an integrated encoder that could be used in our robot car.

After comparison and testing, we selected the BM50 motor. During testing, we found that applying only approximately 14% of the BM50 motor’s power produced a speed similar to that of our previous motor operating at full power. A more detailed comparison is provided in Table IV. Based on this significant performance improvement, we decided to replace the previous motor with the BM50.

Fig. 11. The Pi Camera module 3 wide we used for the Obstacle Challenge.

Fig. 12. The encoder motor we used.

Fig. 9. Ideal and actual discharge curves of primary zinc batteries (Alkaline Zinc cell and Zinc-carbon cell) (Huot, 2009)

Fig. 10. Batteries used for our smart car. Left (blue): 1500

With this upgrade, our robot was able to complete the Open Challenge in just 19 seconds while using only 50% of the BM50 motor’s power. This demonstrates that the BM50 provides a substantial speed reserve, allowing us to achieve faster performance while still maintaining room for further speed adjustment and control optimisation.

Motors | Motor Voltage (V) | No load current (A) | Rated load current (A) | Stall current (A) | Rated speed (RPM) | Stall torque (N · m)
BM50 | 12 | 0.65 | 2.6 | 16 | 4450 | 0.423
MATRIX TT Encoder Motor | 6 | 0.47 | 1.31 | 3.4 | 163 | 0.08
LEGO EV3 Large Motor | 7.4 | 0.07 | 0.5 | 1.8 | 170 | 0.21
LEGO SPIKE Prime Large Motor | 7.2 | 0.135 | 0.43 | 1.4 | 175 | 0.25

From Table IV, we can see that BM50 outperforms all other commonly used motors. Here, we also proved that it is the optimal motor for our robot to participate in the Future Engineers challenges:

Below is a table of the basic information of our robot:

Weight: 0.95kg | Front-wheel radius: 0.028m | Differential gear ratio: 20:28
Targeted acceleration: 0.6m/s² | Rolling coefficient: 0.02 | Differential efficiency: 70%

From Table V, we can then calculate the torque required for the motor we used. The force required for the robot to achieve the given targeted acceleration is given by

0.95 · 0.6 = 0.57N.

Thus, the torque required is

0.57 · 0.028 = 0.01596Nm.

However, the wheels also experience rolling friction between them and the ground. The additional torque required to overcome the friction is given by

0.95 · 9.81 · 0.02 · 0.028 · 2 = 0.01043784Nm,

where the total torque on the wheels is

0.01043784 + 0.01596 = 0.02639784Nm.

Table IV. Comparative summary of the BM50 motor and other commonly used motors, based on key specifications, performance characteristics, and suitability for the robot’s driving system.

Table V. Basic specifications of our robot.

Since the wheels are connected to a mechanical differential, the gear ratio and the efficiency of the differential should also be considered. Therefore, the torque required from the motor is

0.02639784
28/20· 0.7

= 0.02693657143Nm < 0.423Nm.

Therefore, the BM50 is a suitable motor with sufficient torque to drive the robot.

The encoder integrated with the BM50 motor measures the travel distance of the robot by recording the rotation angle of the motor. By converting the encoder readings into wheel rotation and travelled distance, the robot can control its movement more accurately and repeatably.

For example, during the Obstacle Challenge, the robot reverses by a fixed distance after completing each lap. This is achieved by resetting the encoder count and using the encoder feedback to control the backward motion until the required distance is reached.

Since the Raspberry Pi 5 requires a stable 5 V supply, the YB-MPP01-V1.0 buck converter is incorporated into the power system to step down the battery voltage to a suitable level for the Raspberry Pi. The BM50 motor, which operates at 12 V, is powered separately through the motor drive circuit.

## 3.6. Steering motor (CZ356 Servo Motor)

We selected the CZ356 servo motor for the steering system not only because of its compact size, but also because of its LEGO-compatible design. This compatibility allows the servo motor to be mounted easily onto our robot using simple LEGO attachments and structural parts, reducing the need for complex custom-made brackets. As a result, the steering mechanism can be assembled, adjusted, and repaired more conveniently during testing and competition.

The small size of the CZ356 servo motor is also important because our steering system is located at the front of the robot, where space is limited due to the integration of the front-wheel-drive mechanism, differential, and Ackermann steering linkage. A compact servo helps us keep the front assembly lightweight and organised, which improves the overall
balance of the robot and reduces unnecessary load on the steering structure.

Since our robot is lightweight, only a moderate amount of torque is required to rotate the front steering linkage. The CZ356 servo motor provides a torque of 0.16 N·m while operating under a 5 V power supply, which is sufficient for our steering mechanism. This allows the robot to achieve stable and responsive steering without using a larger and heavier servo motor.

In addition, using a 5 V servo motor simplifies the electrical design, as it can be powered from the regulated lowvoltage supply used by other control components. Overall, the CZ356 servo motor provides a suitable balance of size, torque, ease of installation, LEGO compatibility, and electrical simplicity, making it an appropriate choice for the steering system of our robot.

## 3.7. Debug Display (Waveshare 1.3” IPS LCD HAT)

During testing and calibration, a debug display is essential for monitoring the robot’s internal status in real time. We selected the Waveshare 1.3-inch IPS LCD HAT because it provides a compact but clear display that can be mounted directly onto the
robot without occupying much space. Its 240 × 240 resolution is sufficient for showing
key information such as program status, camera detection results, motor speed,
steering angle, battery voltage, lap count, and error messages. | Fig. 15. The monitor we used.

Fig. 14. The CZ356
servo motor.

This display is particularly useful during practice sessions because it allows us to check whether the robot is operating correctly without connecting an external monitor or computer. For example, when tuning the vision algorithm, the display can show whether obstacles, track boundaries, or colour regions are being detected correctly. When testing the driving system, it can also show encoder readings, selected speed settings, or whether the robot is currently in start, stop, calibration, or running mode.

In addition, the HAT includes three push buttons, which provide a simple physical interface for controlling the robot. These buttons can be programmed to start or stop the robot, switch between testing modes, reset values, or trigger calibration procedures. This makes repeated testing more efficient, as we can control the robot directly from the onboard interface instead of modifying the program or reconnecting to the Raspberry Pi each time.

## 3.8. Build Of Materials and Wiring Diagrams

### 3.8.1. Build Of Materials

Label | Quantity | Name
BT1 | 3 | 18650
M1 | 1 | BM50
M2 | 1 | Motor_Servo
Module1 | 1 | Raspberry Pi 5
U1 | 1 | ESP32-S3-DevKitC
U2 | 1 | Pi Cam 3
U6 | 1 | BM50 Motor Driver Encoder
U8 | 1 | YB-MPP01-V1.0
U9 | 1 | ST7789 HAT

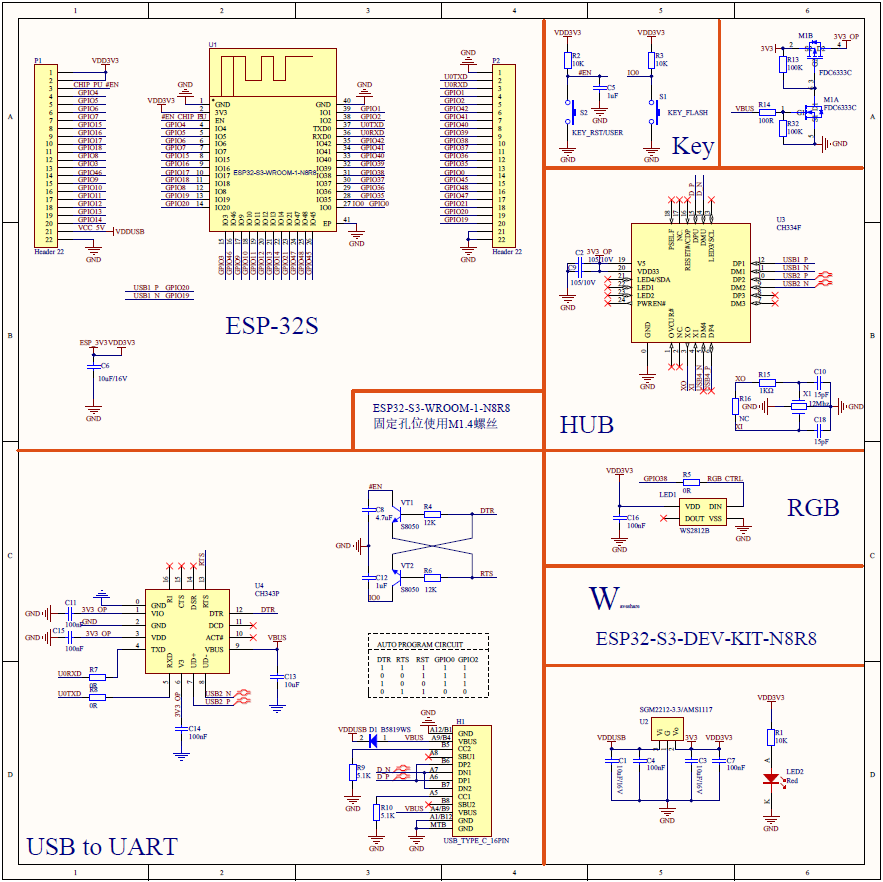
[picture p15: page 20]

### 3.8.2. Schematic of ESP32-S3

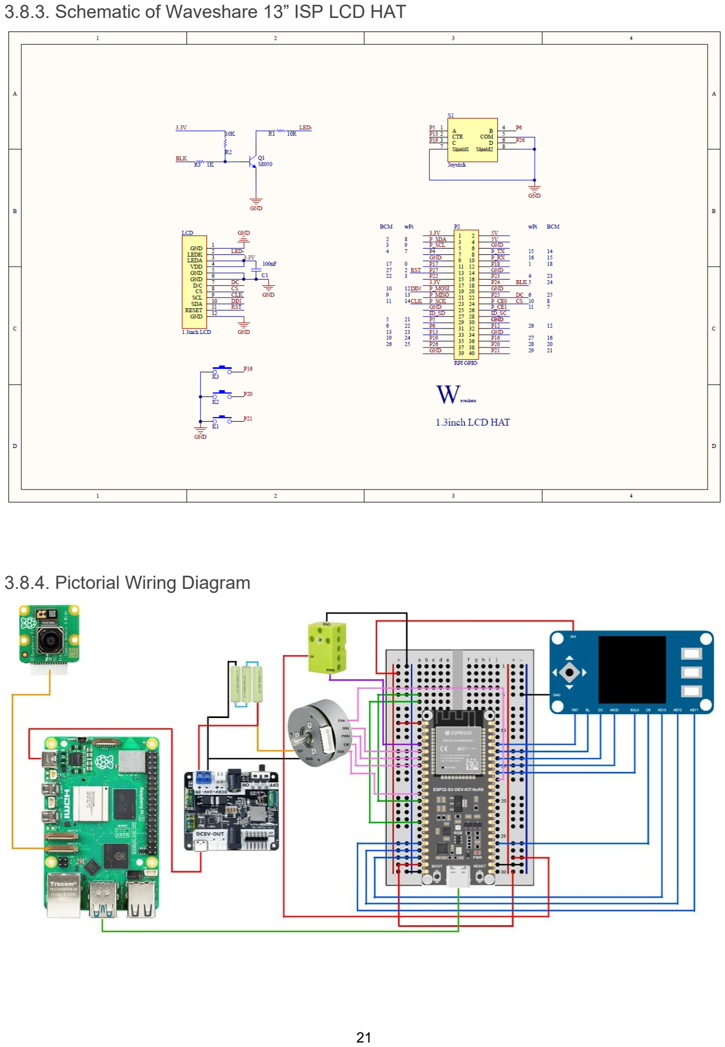
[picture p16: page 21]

### 3.8.3. Schematic of Waveshare 13” ISP LCD HAT

### 3.8.4. Pictorial Wiring Diagram

### 3.8.5. Schematic Wiring Diagram

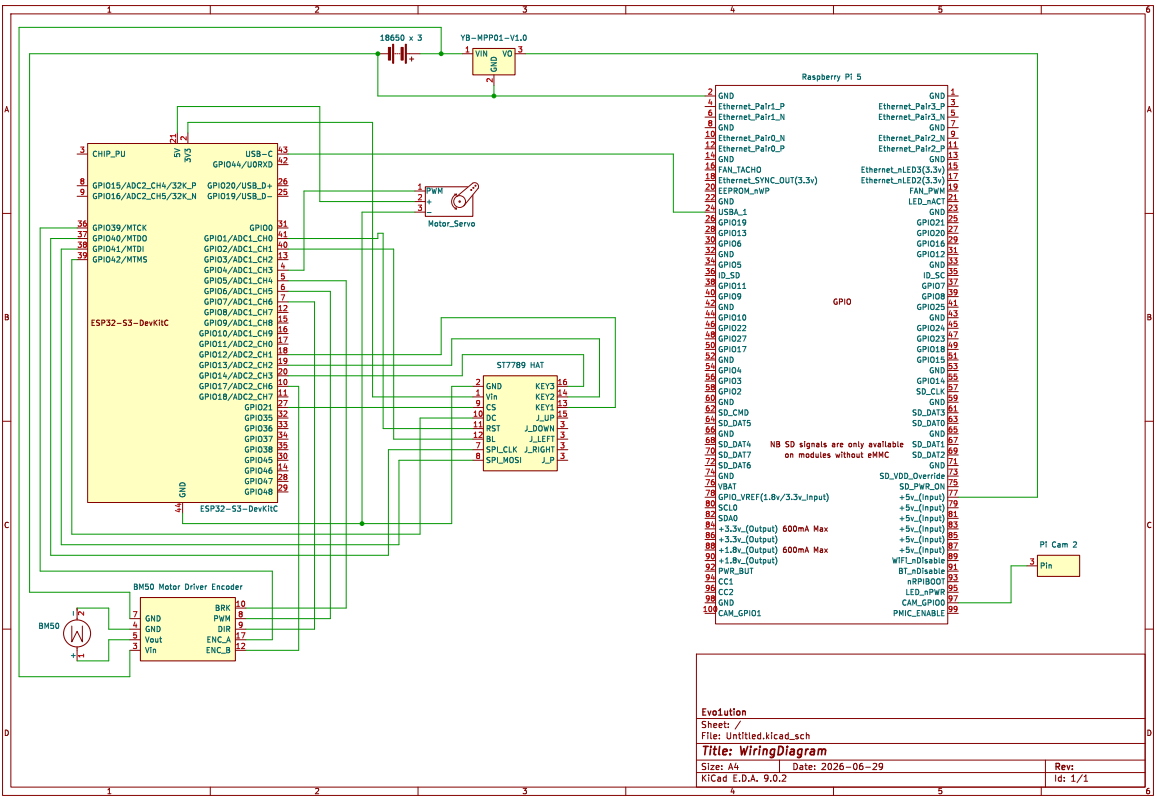
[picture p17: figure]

# 4. Obstacle Management

To minimise workload and conserve computing resources during multitasking, we use the ThreadController library to manage task execution efficiently. Instead of creating a large number of threads, we only create the essential ones required for key functions. This reduces unnecessary context-switching overhead and helps maintain stable real-time performance.

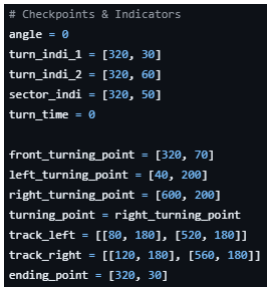
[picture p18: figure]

As mentioned above, the Raspberry Pi is responsible for analysing camera feedback. After receiving images from the camera, the Raspberry Pi applies different image-processing filters to identify and highlight important features, including the track, obstacles, and the parking lot. Based on the processed image data, the Raspberry Pi then checks whether specific conditions are fulfilled and determines the current state of the vehicle.

After the vehicle state has been determined, the Raspberry Pi sends the corresponding control command to the ESP32-S3. The ESP32-S3 then controls the driving motor and steering servo according to the received command. This division of tasks allows the Raspberry Pi to focus on image processing and high-level decision-making, while the ESP32-S3 handles low-level motor control more efficiently.

## 4.1. Open Challenge (OC1)

In OC1, the only unknown parameter is the lap direction, which can be either clockwise or anticlockwise. Using camera feedback, the robot initially travels straight until the visual indicators marked on the camera frame detect the track condition required to determine the direction of the challenge. After the first turn has been completed, the robot follows the inner wall with the aid of a PID algorithm. This allows it to maintain a suitable distance from the wall while continuing to move forward stably. After completing 12 turns, corresponding to three laps, the robot stops in the end-of-game sector.

Fig. 18. Example of our program code showing the operating states used in the robot’s state machine.

Fig. 17. Example of our program code showing how checkpoints are used to track the robot’s progress and control its behaviour during the challenge.

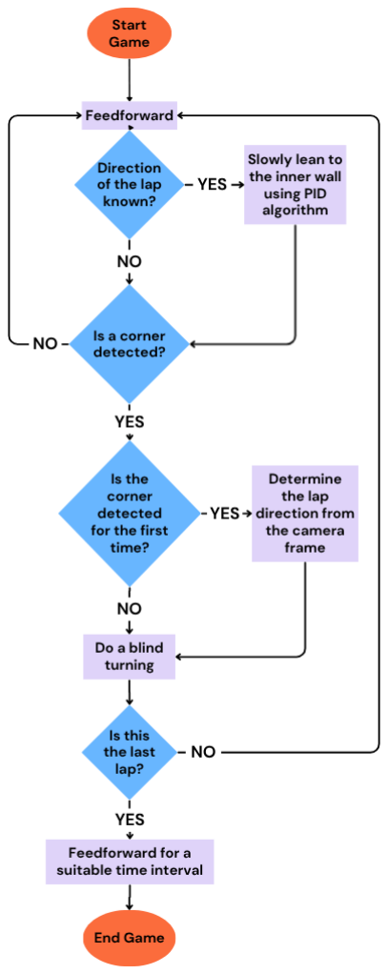
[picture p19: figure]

Fig. 19. Flow chart of our program for the Open Challenge

Fig. 16. Results of the image-processing filters used to detect and highlight key visual features, including track boundaries, obstacles, and the parking area.

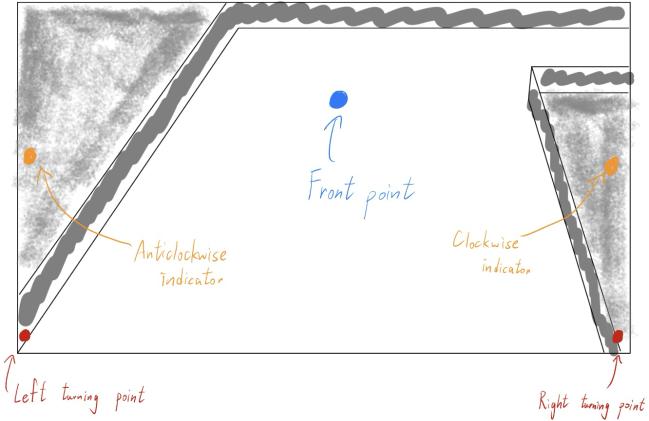
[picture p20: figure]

Figure 20 shows the indicators marked on the camera frame. The Left Turning Point (LTP), Right Turning Point (RTP), and Front Point (FP) are used to determine whether a turn is available. The Anticlockwise Indicator (AI) and Clockwise Indicator (CI) are used to determine the direction of the challenge. When the robot is in a position where it should continue moving straight, the FP lies inside the white track, while the LTP and RTP lie outside the white track.

The robot identifies a turnable corner when the FP lies outside the track and one of the turning points, either the LTP or RTP, lies inside the white track. At the same time, one of the direction indicators also lies inside the track, allowing the robot to determine whether it should turn clockwise or anticlockwise, as illustrated in Figure 21.

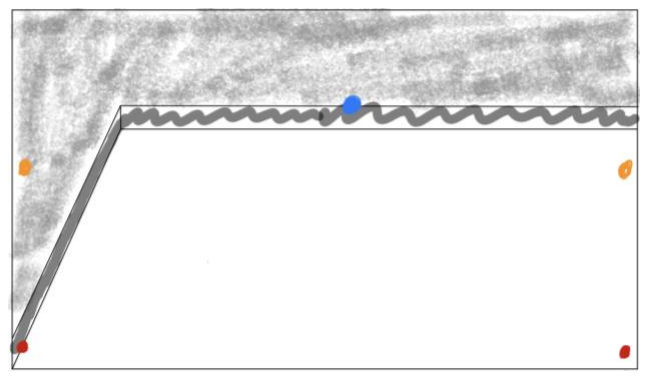
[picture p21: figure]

Once a turn is detected, the robot performs a blind turn using a preset timer. The turning duration is intentionally set to be slightly shorter than the time required to complete the full turn. After this partial turn, the robot calculates its distance from the inner wall and uses the PID algorithm to gradually move closer to it. A conservative PID setting is used to prevent the robot from crashing into the inner wall. The purpose of following the inner wall is to shorten the travelling distance and reduce the total time required
to complete the challenge.

Using the same logic, the robot records the number of completed turns until it reaches 12 turns, which corresponds to three full laps. It then moves forward for a fixed time interval and stops within the starting sector.

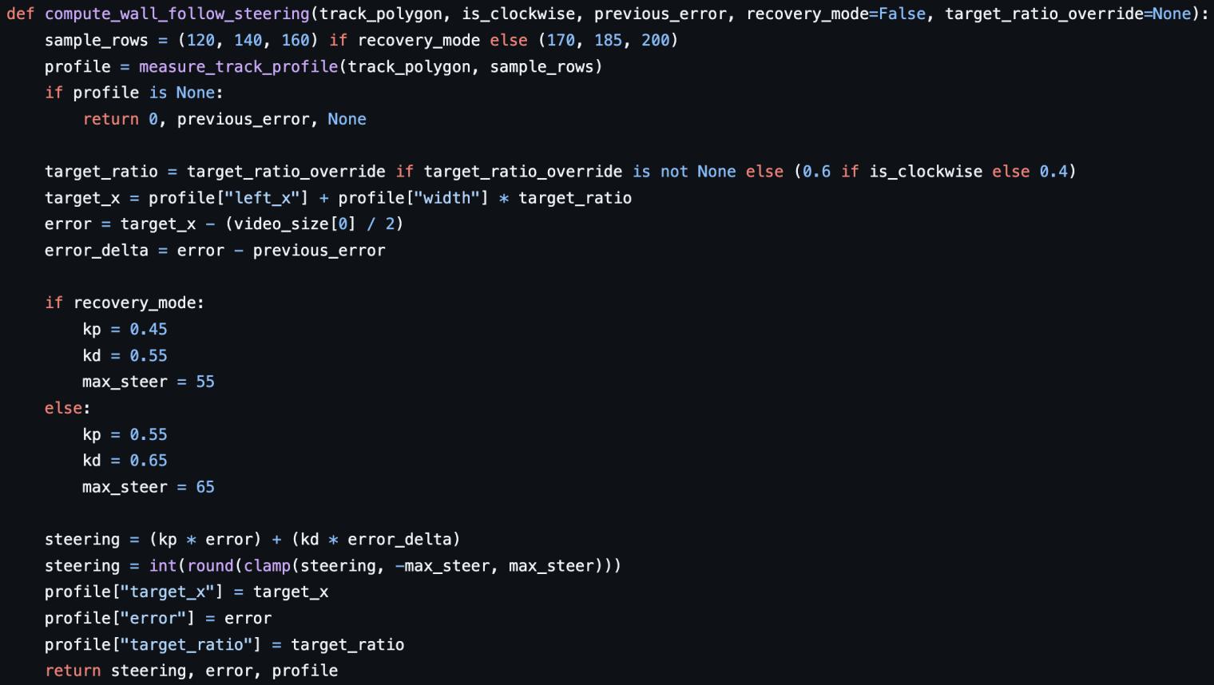
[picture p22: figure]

Fig. 22. Code segment showing how the robot uses a PID algorithm to lean toward the inner wall. The program first measures the relative distance from the inner wall, then calculates the steering correction based on the distance error and the change in error, using the preset (kp) and (kd) values. A maximum steering limit is also applied to prevent excessive correction.

Fig. 20. Diagram illustrating the definition of the indicators and the locations at which they are marked.

Fig. 21. Diagram illustrating the condition under which the robot determines that a turn is available.

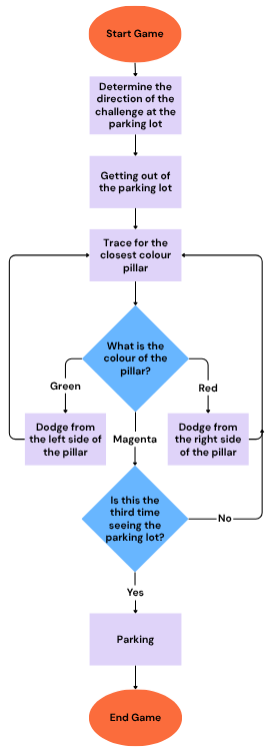
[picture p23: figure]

## 4.2. Obstacle Challenge (OC2)

In OC2, the lap direction is easier to determine because the robot starts inside the parking lot. By analysing the camera image at the beginning of the run, the robot can identify whether the challenge direction is clockwise or anticlockwise. While exiting the parking lot, the robot continuously checks for coloured obstacles. If an obstacle is detected, it performs an avoidance manoeuvre and then proceeds forward until it detects the inner barrier. It then reverses by a fixed distance to obtain a wider field of view and assess whether an obstacle is present immediately after the corner.

Our control logic for OC2 is based on detecting and responding to the closest coloured obstacle visible to the camera. When an obstacle is detected, the robot determines the correct side from which to avoid it according to the obstacle colour, using the steering formula introduced in the following paragraph. Since the robot already knows the direction of the challenge, if no coloured obstacle is detected but a dead end is identified ahead, the robot turns in the correct direction of the track: left for anticlockwise and right for clockwise.

The robot also records the number of times it detects the magenta parking lot. Once this count reaches three, indicating that the robot has completed the required number of laps, it executes the parking function and performs the parallel parking manoeuvre.

To maintain a suitable distance from each obstacle, we developed formulas to calculate the desired avoidance path, as shown in Figure 24. When an obstacle is detected, the coordinates of its midpoint are recorded. The robot then selects the appropriate formula according to the obstacle colour and calculates the required steering percentage. For example, if the midpoint of a red obstacle is located at (100, 100), the calculated steering percentage is (-140%). Since the steering output is limited to the valid control range, this value is capped at (-100%), causing the robot to steer left and avoid the
obstacle from the correct side.

When no obstacle is detected, the robot continues moving forward using the stable wall-following strategy developed for OC1. This process is repeated sector by sector until the robot completes the third lap. After that, it returns to the parking lot and executes the final parking manoeuvre.

Fig. 23. Flow chart of our program for the Obstacle Challenge.

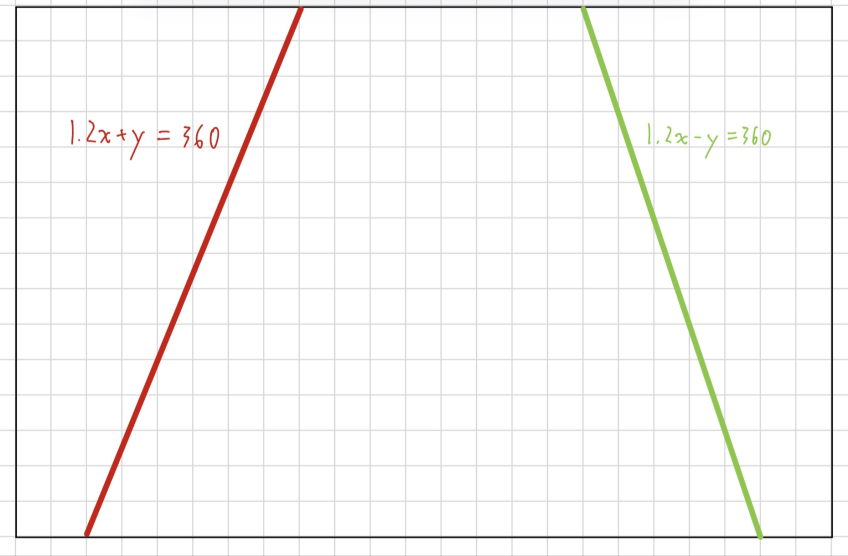
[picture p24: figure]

Fig. 24. The formulas of the ideal track for the green and red obstacles.

# 5. Vehicle Photos

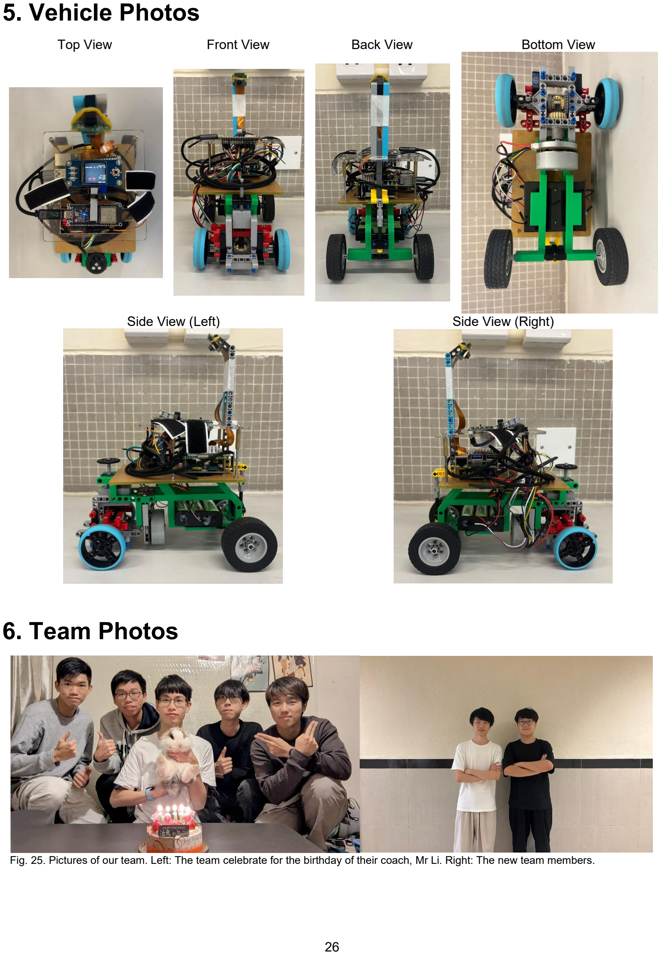
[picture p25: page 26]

Top View | Front View | Back View | Bottom View
Side View (Left) | Side View (Right)

# 6. Team Photos

Fig. 25. Pictures of our team. Left: The team celebrate for the birthday of their coach, Mr Li. Right: The new team members.

# 7. Performance Video and GitHub Repository

Scan the QR code for our practice videos!

Open Challenge
Performance Video

Obstacle Challenge
Performance Video

Our GitHub Repository
Latest working branch: Gen-1.0

# 8. References

Huot, J.-Y. (2009). Zinc. In Encyclopedia of Electrochemical Power Sources (pp. 883–892). Amsterdam: Elsevier.

# A. Appendix

## A.1. What we learned

In addition to studying real-world vehicles, we consulted a professional race car engineer, Mr Lewis Wong, and incorporated the following key insights:

- Slip-angle optimisation is unnecessary for a robot of this scale, and the incremental benefit of Ackermann steering is limited; nonetheless, we implemented a simple LEGO-based Ackermann mechanism for demonstration and modest performance gains.
- A differential is highly beneficial, as it significantly smooths low-speed turning despite a slight reduction in straight-line speed.
- A shorter wheelbase improves turning agility and overall manoeuvrability.
- A wider front track than rear track during cornering enhances smoothness, although we did not implement this due to chassis-width constraints.
- Lightweight wheels increase top speed more effectively than reducing overall vehicle mass.
- Smaller wheel diameters further improve manoeuvrability.
- A low centre of mass is critical for stability.
- An onboard gyro is essential for precise heading estimation and reliable lap counting.
- Storing pillar colours in an array upon first detection enables faster decision-making on subsequent passes.
- Reducing camera resolution, where image quality remains sufficient, increases frame rate and improves responsiveness.

## A.2. Difference between our robot for the Hong Kong Regional competition and the current robot

| Old design | Current design

Photo

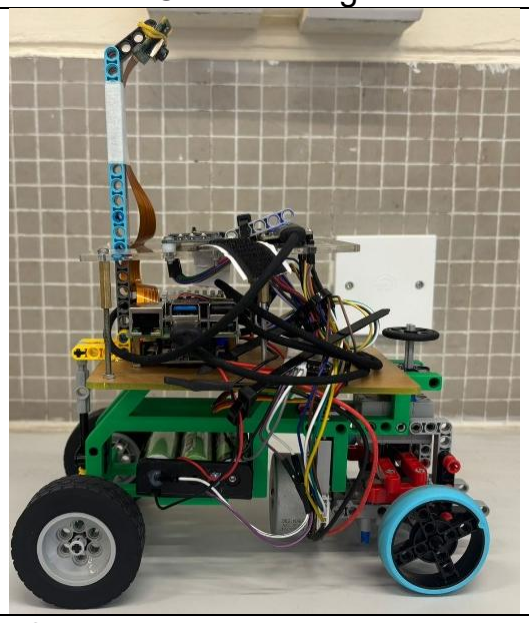
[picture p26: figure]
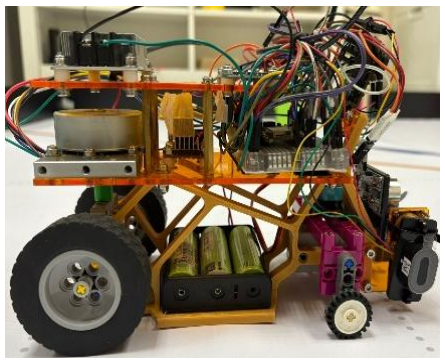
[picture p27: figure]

Major chassis materials | Self-designed 3D-printed components and acrylic plates | Self-designed 3D-printed components and acrylic plates
Driving motor & en-coder | BM50 brushless motor with encoder | BM50 brushless motor with encoder
Servo motor | CZ356 | CZ356
Camera | Camera (PixyCam2.1) | Raspberry Pi Camera Module 3 wide
Time of Flight sensor (ToF) | STP-23L
IMU | ICM-20948
Controller | ESP32 | ESP32, Raspberry Pi
Advantages | • Easier algorithm design | • Simpler connection of electronic components
Disadvantages | • Unstable performance | • Difficult to design the algorithm to identify the state using camera feedback only

## A.3. How Wheels Affect a Car's Performance?

After discussing with Lewis and conducting further research, we identified numerous factors that influence a car’s performance. We begin with the wheels.

Wheels

Toe-in and toe-out: Toe-in occurs when the front edges of the wheels are closer together than the rear edges, improving straight-line stability. Toe-out is the opposite, with the front edges farther apart than the rear. As we aim to use simple mechanisms and structures, and we expect toe settings to have only a minor effect at our scale, we chose not to implement adjustable toe on the robot.

Camber (positive and negative): Positive camber means the top of the wheel tilts away from the vehicle, which can enhance stability at high speeds and on rough surfaces. Negative camber means the top of the wheel tilts toward the vehicle, improving grip and handling in corners because the outside tyre maintains a larger contact patch with the ground. Most real vehicles, not just race cars, use some degree of negative camber. Initially, we did not intend to incorporate camber for the same “simplicity” reasons. However, because LEGO parts are slightly elastic, our structure unintentionally introduced a small negative camber. We have not quantified the difference between zero and negative camber on our robot, but we have observed no adverse effects and therefore kept the current configuration.

Tyre size and configuration: Using an F1 car as a conceptual reference, and given that our drive motor provides high torque and strong acceleration in a rear-wheel-drive layout, we selected larger and wider rear tyres. The increased contact patch improves traction and helps prevent wheelspin during acceleration. For the front wheels, we chose smaller, narrower tyres, as they are primarily responsible for steering. A smaller contact patch and lower tyre mass enhance steering responsiveness and reduce the load on the steering motor. In practice, the available front-wheel grip is sufficient to prevent understeer during cornering.

Wheelbase: As discussed earlier, a shorter wheelbase reduces the turning radius and improves agility. However, if the wheelbase is too short, the car becomes prone to understeer and can actually corner worse. Our goal was, therefore, to find an optimal compromise between a compact wheelbase and acceptable understeer characteristics.

Wheel weight: Lewis emphasised that wheel mass is critical. Theoretically, adding 10 g to each wheel has a greater impact on performance than adding 40 g to the car body, because rotating mass is more influential than static mass. In our case, we are not building a full-scale race car, and typical LEGO wheel weights are relatively small. As a result, using a 30 g wheel instead of an 8 g wheel is unlikely to be a decisive factor in our competition performance unless the wheel weight becomes extremely large (on the order of 200 g per wheel).

Track width: Track width is the distance between the centrelines of the wheels on the same axle. A wider track width improves lateral stability and allows higher cornering speeds and cornering stiffness. However, we chose not to maximise the track width (20 cm) on our robot. Some corners on the field are quite narrow, and a wider track would increase the likelihood of hitting the walls or colour blocks. A very wide track would also be disadvantageous when manoeuvring in the parking lot.

Steering geometry and maximum steering angle: Real cars employ Ackermann steering geometry, where the inner front wheel turns more than the outer one in a corner, reducing tyre scrub and improving grip. Although it is difficult to implement a perfect Ackermann system using LEGO parts, we designed a simplified version inspired by kart steering. This solution is lightweight and provides a modest but meaningful performance benefit. We also needed to select an appropriate maximum steering angle. An excessively large steering angle can induce apparent understeer and significantly reduce cornering speed, making the car feel as if it lacks power in turns. Ultimately, we chose a moderate steering angle that allows the robot to clear all corners on the field without excessive understeer.

Tyre material and surface grip: In full-scale motorsport, when track and weather conditions are favourable, engineers fit slick tyres (without tread) that soften at high temperatures to maximise grip. For our robot, the WRO field surface is relatively smooth, so using softer tyres with a defined tread pattern helps increase friction and reduce wheelspin during acceleration. If the front wheels were made of a much harder material, understeer could occur due to insufficient grip. In practice, we did not systematically test different tyre compounds, as we preferred to allocate more time to other aspects of robot design and programming.

Other Performance Factors

Beyond wheel characteristics, several additional factors significantly affect performance, including overall weight, centre of gravity, and aerodynamics.

We actively reduced the robot’s mass by using 3D-printed components for the chassis and main structure, allowing us to remove redundant parts and minimise LEGO usage. We also positioned the heaviest component—the batteries and battery box (167 g total)—as low as possible in the chassis to lower the centre of gravity and improve stability.

By contrast, we chose not to consider aerodynamic effects in our design. The robot’s speed is relatively low, so aerodynamic drag is effectively negligible. We do not expect race outcomes to hinge on differences as small as 0.01 seconds, and thus prioritised mechanical design and control algorithms over aerodynamic optimisation.

## A.4. Difficulties

During the Hong Kong regional selection and practice period, we encountered a number of challenges. Below, we describe the main difficulties and how we addressed them.

Practice venue

The WRO Future Engineer field measures approximately 3 m × 3 m. In Hong Kong, space is limited: we could not keep a full-size field set up at home. Fortunately, our alma mater is willing to let us share the field with their team. Although we can only work within the school's operating hours, it is the best venue we can find so far.

Time constraints

We are highly motivated to achieve a strong result at this competition. However, all team members are full-time university students, so our availability is limited. In practice, we can only train on weekends. Even then, family commitments and social gatherings sometimes further reduce our training time.

Our coach is an MPhil student who must balance coursework, research, and departmental responsibilities. Our supporter is a full-time teacher who is only available on weekends. Consequently, our preparation required careful scheduling, efficient use of limited training hours, and strong commitment from every member of the team.

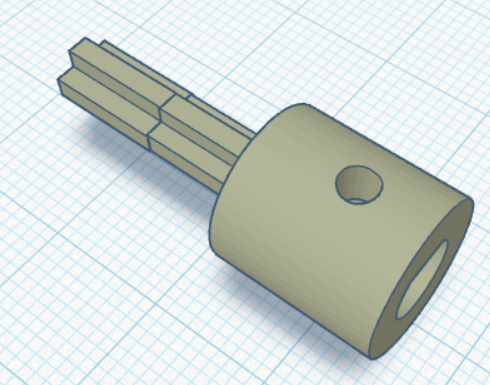
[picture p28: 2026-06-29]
CAD/D2LEGO_shaft_converter_CNC.png

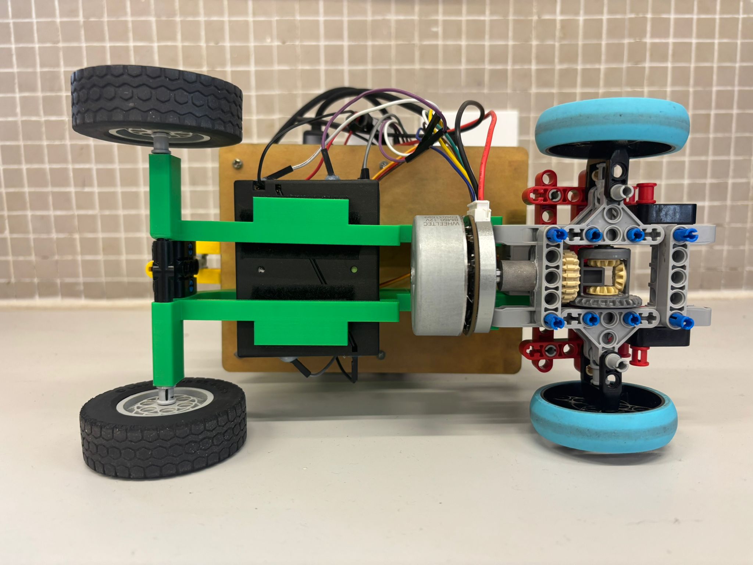
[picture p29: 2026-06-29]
vehicle_photos/Bottom.jpeg

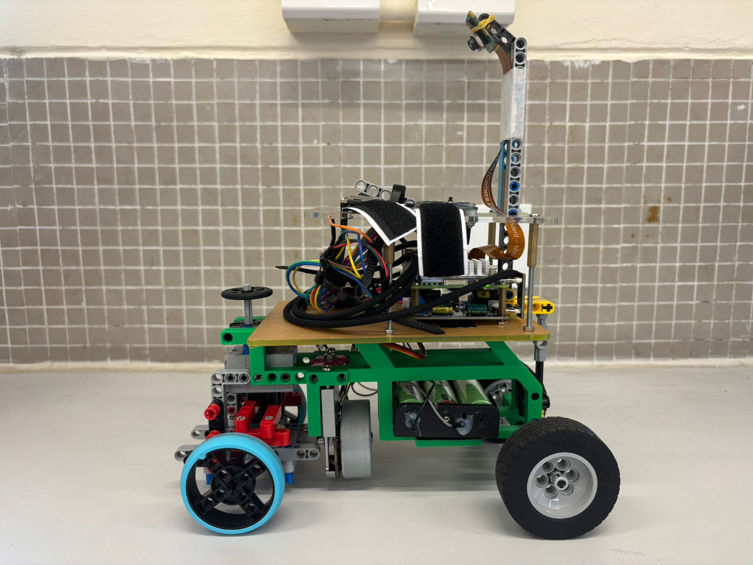
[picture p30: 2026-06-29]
vehicle_photos/Left.jpeg

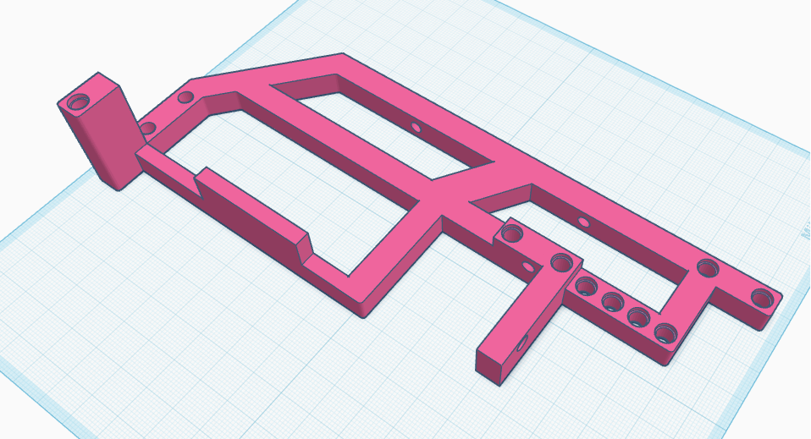
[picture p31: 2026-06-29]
CAD/3dp_right_frame.png

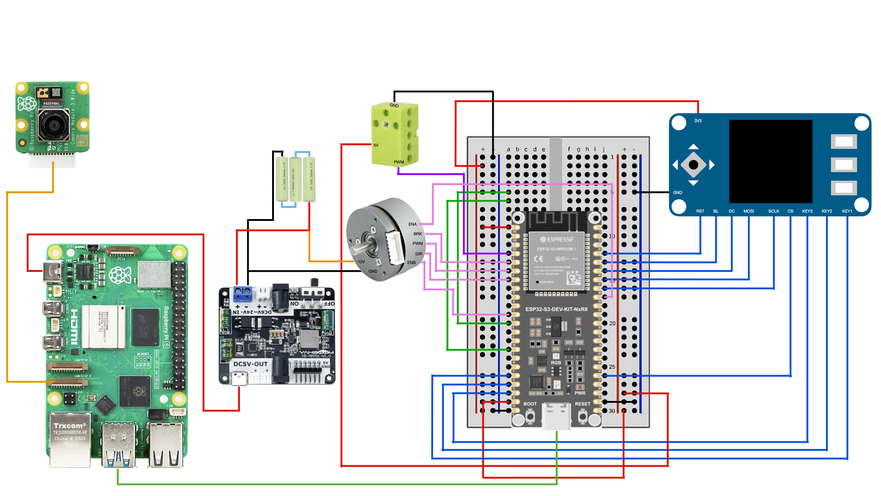
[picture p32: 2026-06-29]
schemes/pictorial_diagram.jpeg

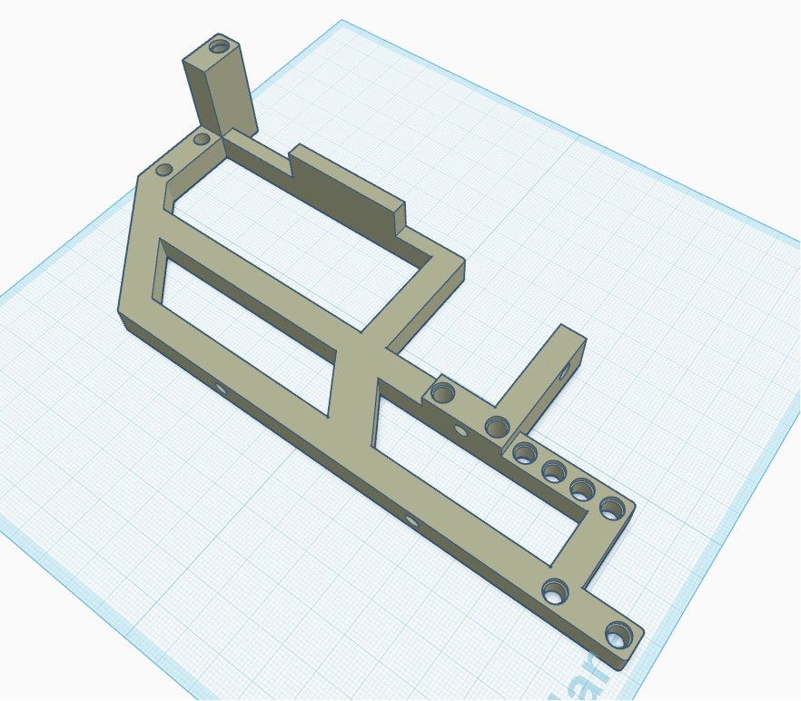
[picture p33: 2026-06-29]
CAD/3dp_left_frame.png

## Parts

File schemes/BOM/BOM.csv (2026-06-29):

Reference | Qty | Value | DNP | Exclude from BOM | Exclude from Board | Footprint | Datasheet
BT1 | 1 | 18650 x 3 |  |  |  |  | ~
M1 | 1 | BM50 |  |  |  |  | ~
M2 | 1 | Motor_Servo
Module1 | 1 | Raspberry Pi 5 |  |  |  | CM5IO:Raspberry-Pi-5-Compute-Module
U1 | 1 | ESP32-S3-DevKitC |  |  |  | PCM_Espressif:ESP32-S3-DevKitC
U2 | 1 | Pi Cam 3 |  |  |  | Package_DFN_QFN:WQFN-42-1EP_3.5x9mm_P0.5mm_EP2.05x7.55mm
U6 | 1 | BM50 Motor Driver Encoder
U8 | 1 | YB-MPP01-V1.0 |  |  |  | Package_TO_SOT_SMD:TO-252-2
U9 | 1 | ST7789 HAT

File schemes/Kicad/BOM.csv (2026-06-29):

Reference | Qty | Value | DNP | Exclude from BOM | Exclude from Board | Footprint | Datasheet
BT1 | 1 | 18650 x 3 |  |  |  |  | ~
M1 | 1 | BM50 |  |  |  |  | ~
M2 | 1 | Motor_Servo |  |  |  |  | http://forums.parallax.com/uploads/attachments/46831/74481.png
Module1 | 1 | Raspberry Pi 5 |  |  |  | CM5IO:Raspberry-Pi-5-Compute-Module
U1 | 1 | ESP32-S3-DevKitC |  |  |  | PCM_Espressif:ESP32-S3-DevKitC
U2 | 1 | Pi Cam 3 |  |  |  | Package_DFN_QFN:WQFN-42-1EP_3.5x9mm_P0.5mm_EP2.05x7.55mm | http://www.ti.com/lit/ds/symlink/ts3l501e.pdf
U6 | 1 | BM50 Motor Driver Encoder
U8 | 1 | YB-MPP01-V1.0 |  |  |  | Package_TO_SOT_SMD:TO-252-2 | https://fscdn.rohm.com/en/products/databook/datasheet/ic/power/linear_regulator/bdxxfc0wefj-e.pdf
U9 | 1 | ST7789 HAT

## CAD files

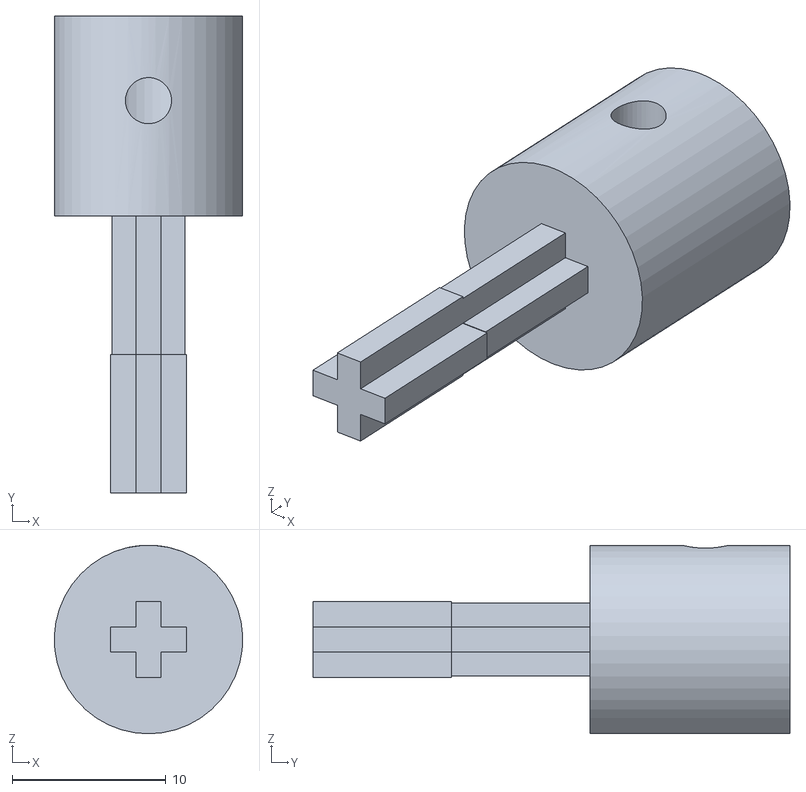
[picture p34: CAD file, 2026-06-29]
CAD/D2LEGO_shaft_converter.STL
12.2 x 31.0 x 12.2

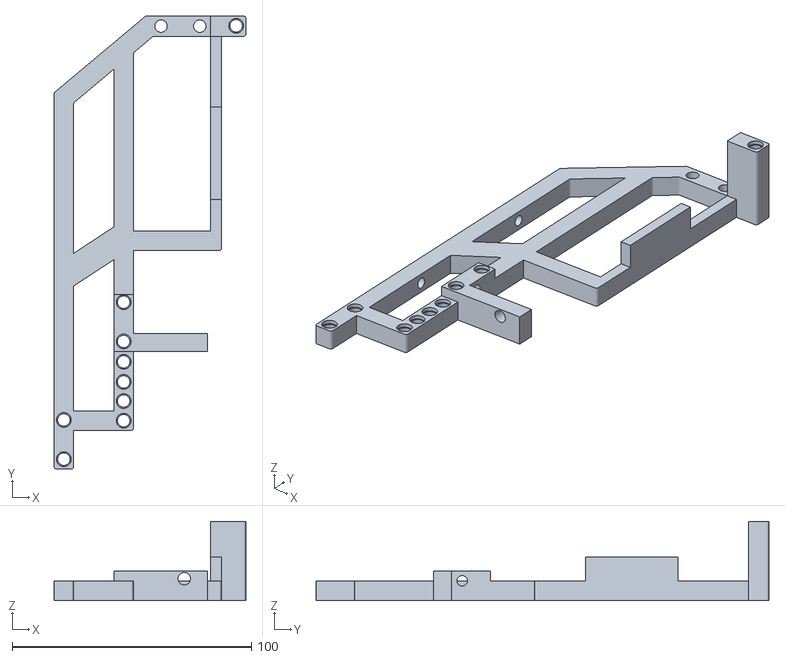
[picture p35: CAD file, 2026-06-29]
CAD/3dp_left_frame.stl
80.2 x 189.3 x 33.2

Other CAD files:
CAD/3dp_right_frame.stl

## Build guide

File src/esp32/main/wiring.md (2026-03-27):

### SPI LCD (ST7789 HAT)

* SCLK (1st row, pin 12) → **GPIO40**
* MOSI (1st row, pin 10) → **GPIO41**
* CS (2nd row, pin 12) → **GPIO21**
* DC (2nd row, pin 11) → **GPIO42**
* RST (1st row, pin 7) → **GPIO1**
* BL (2nd row, pin 9) → **GPIO2** (drive HIGH to turn backlight on)
* VCC (1st row, pin 1) → 3V3
* GND (2nd row, pin 3) → GND

### HAT Buttons & Joystick  *(active-LOW, use `INPUT_PULLUP`)*

* KEY1 (2nd row, pin 20) → **GPIO12**
* KEY2 (2nd row, pin 19) → **GPIO13**
* KEY3 (2nd row, pin 18) → **GPIO14**
(UNUSED) * JOY UP → **GPIO15**
(UNUSED) * JOY DOWN → **GPIO16**
(UNUSED) * JOY LEFT → **GPIO17**
(UNUSED) * JOY RIGHT → **GPIO18**
(UNUSED) * JOY PRESS → **GPIO11**

### Qwiic IMU (ICM-20948, I²C @ 3.3 V), share with Pixy2

* SDA → **GPIO8** (purple)
* SCL → **GPIO9**
* VCC → 3V3, GND → GND

### Pixy 2.1 (UART)

* SDA (3rd row, pin 1) → **GPIO8**
* SCL (5th row, pin 1) → **GPIO9**
* VCC (1st row, pin 2) → 5V
* GND (3rd row, pin 2) → GND

### ToF  *(power both from 5 V)*

* ToF 1 (Left): **TX → GPIO10**, **RX → GPIO11**
* ToF 2 (Left): **TX → GPIO48**, **RX → GPIO47**

### BM50 brushless motor with encoder
* Brake (blue) → **GPIO5**
* PWM (green) → **GPIO6**
* Dir (brown) → **GPIO7**
* ENCPinA → **GPIO39** (yellow)
* ENCPinB → **GPIO17** (white)

### Servo

* Signal (orang) → **GPIO4** (LEDC @ 50 Hz)
* Power servo (red) from 5–6 V (not 3V3); GND (brown) common

### HC-SR04 x2  *(power both from 5 V; **ECHO must be level-shifted to 3.3 V**)*

* (UNUSED) Sensor A (Left): **TRIG → GPIO10**, **ECHO → GPIO11** (through resistor divider)
* (UNUSED) Sensor B (Right): **TRIG → GPIO47**, **ECHO → **GPIO48** (through resistor divider)
* (UNUSED) Sensor C (Front): **TRIG → GPIO15**, **ECHO → **GPIO16** (through resistor divider)

#### Notes / gotchas

* **Do not use**: GPIO0 (BOOT strap), **GPIO19/20** (USB D−/D+), **GPIO45/46** (input-only; avoid for TRIG/PWM).

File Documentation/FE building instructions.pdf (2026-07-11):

Building instruction
Step 1:

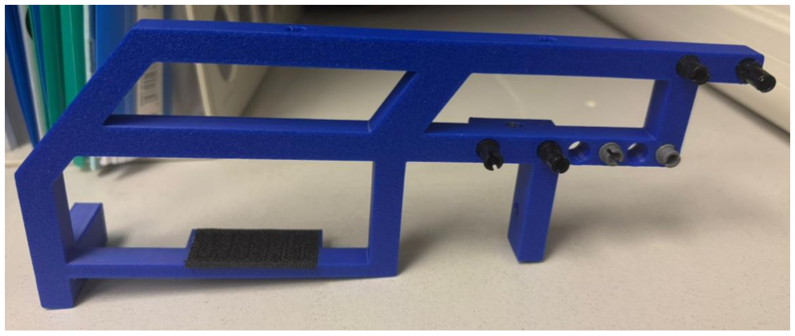
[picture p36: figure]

Figure 1 : Step 1 Right-side finishing frame
First, plug 4 Lego connector peg with friction, 2-module and 2 Lego 1 1/2 connecting bush into the holes shown in the above figure. Do the same thing to the left sided car frame.
Step 2 :

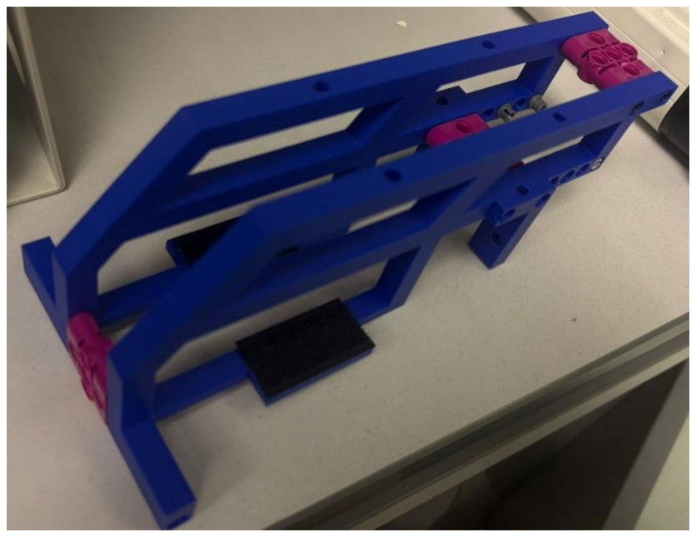
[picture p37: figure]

Figure 2: Step 2 finishing figure

Then, put 2 frame together and connector with 3 Lego technic pin connector block 1x3x3 module like the figure shown.

Step 3 :

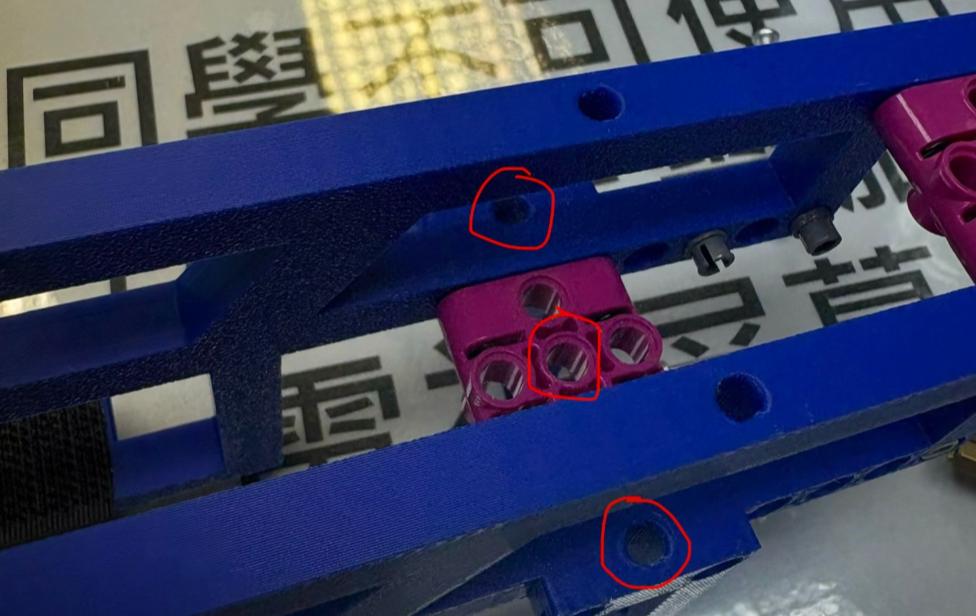
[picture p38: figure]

Figure 3 : Figure for locking the motor tips

3 M4 socket head screws are placed in the holes drawn with red circles, showing in the above figure. They are used for fixing up the moving motor.
Step 4 :

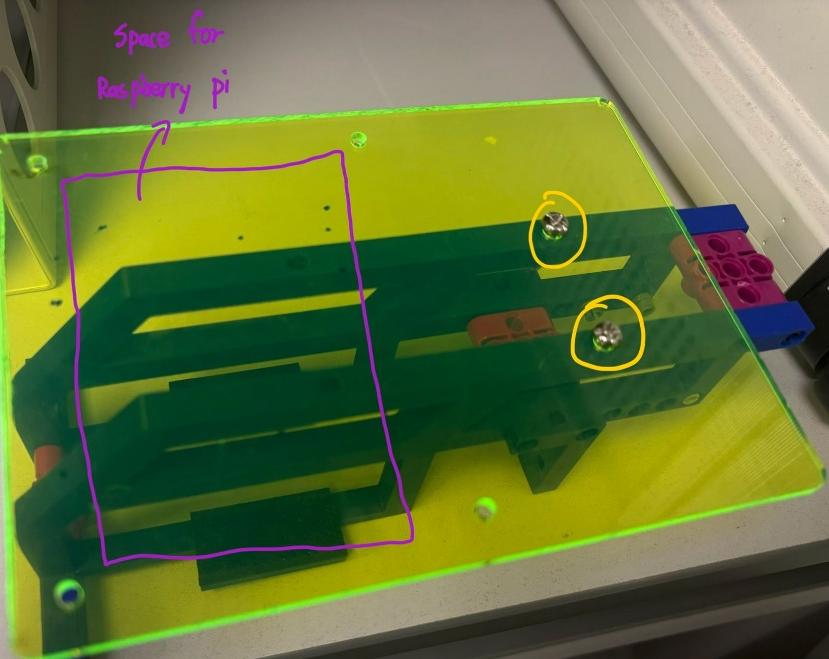
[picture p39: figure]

Figure 4 : Space for Raspberry Pi (Purple rectangle), M4x15 socket screws (yellow circles)
Next, place the laser cut middle plate on the top of 2 side car frame and then use 2 M4 x15 socket head screw and 2 lock nuts to fix the plate and frame as shown as the hole with yellow circles in the above figure.

Step 5:

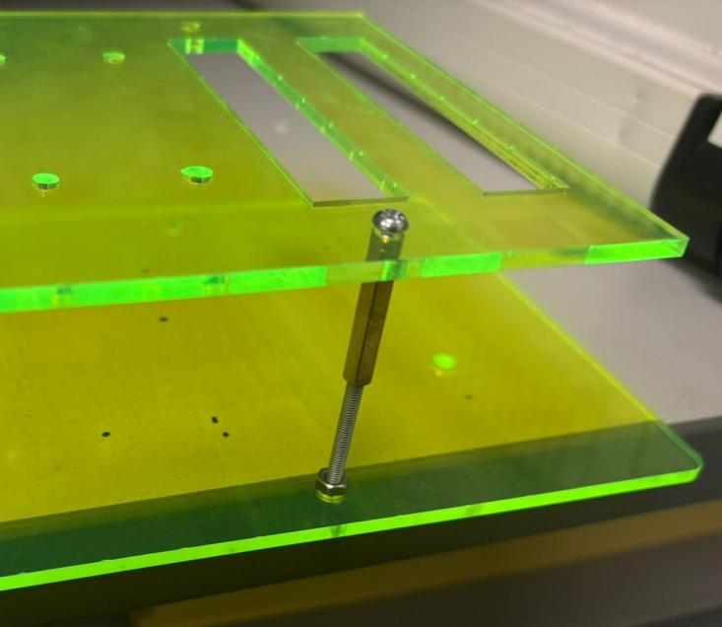
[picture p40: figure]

Figure 5 : finishing step 5

Next, use 1 M3 x 40 ,1 M3 x 15 socket head screw and 1 M3 Double Through Brass Standoffs Screws Hex Spacer Standoffs to fix the laser cut middle plate and the top plate. M3 x 40 passes through the hole on the middle plate and M3 x 15 socket head screw passes trough the top plates. Two screws are connector by the hex spacer standoffs.

Step 6 :

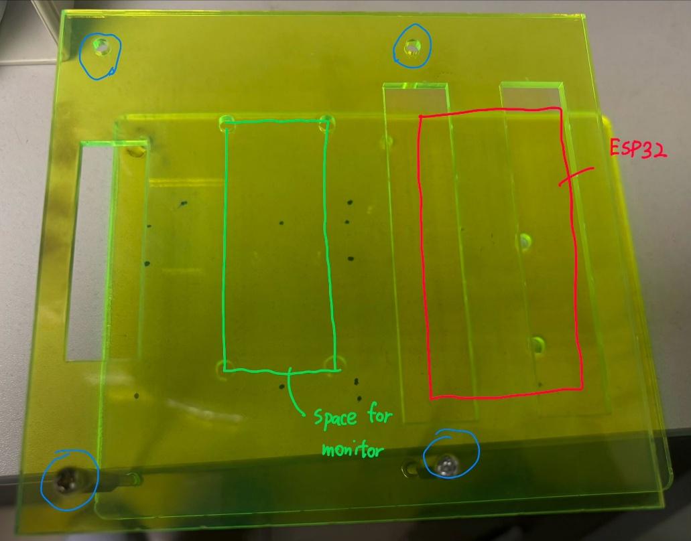
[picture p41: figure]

Figure 6 : Hints for placing monitor and ESP32
Last, repeat step 5 for 3 times for other 3 holes circling with blue color in the figure shown above. Place the monitor

(green rectangle box) and fix with 4 M3 socket head screws. For the ESP32, place at the space drawing in red rectangle box.

Tips for fixing ESP32 ,Raspberry Pi and the battery box All these 3 electronic components are fixed by hook and loop fasteners. Demonstration diagrams are shown below.

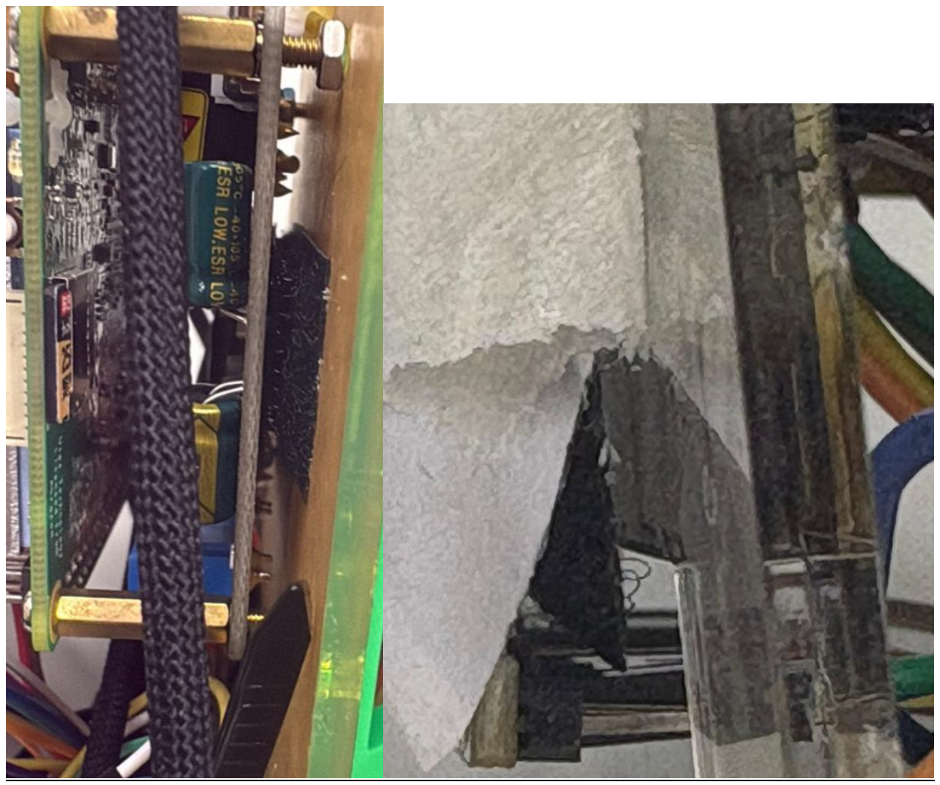
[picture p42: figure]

Figure 7&8 : Demonstration of the hook and loop fasteners

For the differential part, it is fixed on the steering servo and also connector with the moving motor.

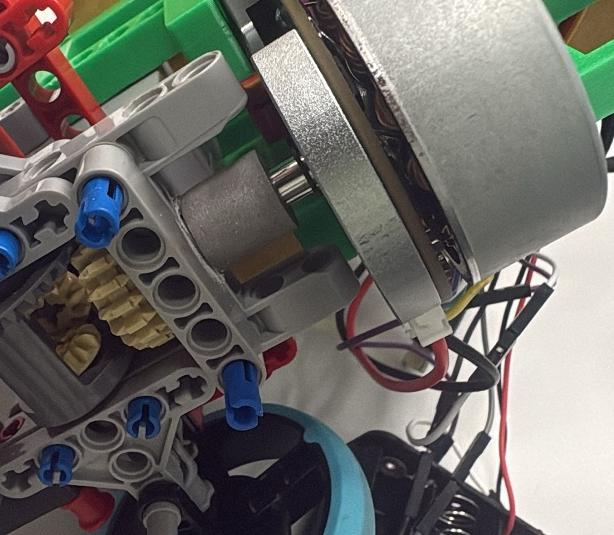
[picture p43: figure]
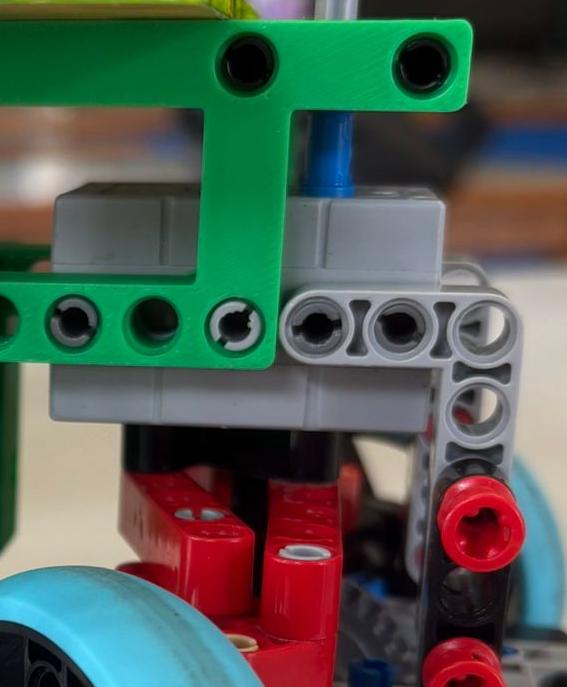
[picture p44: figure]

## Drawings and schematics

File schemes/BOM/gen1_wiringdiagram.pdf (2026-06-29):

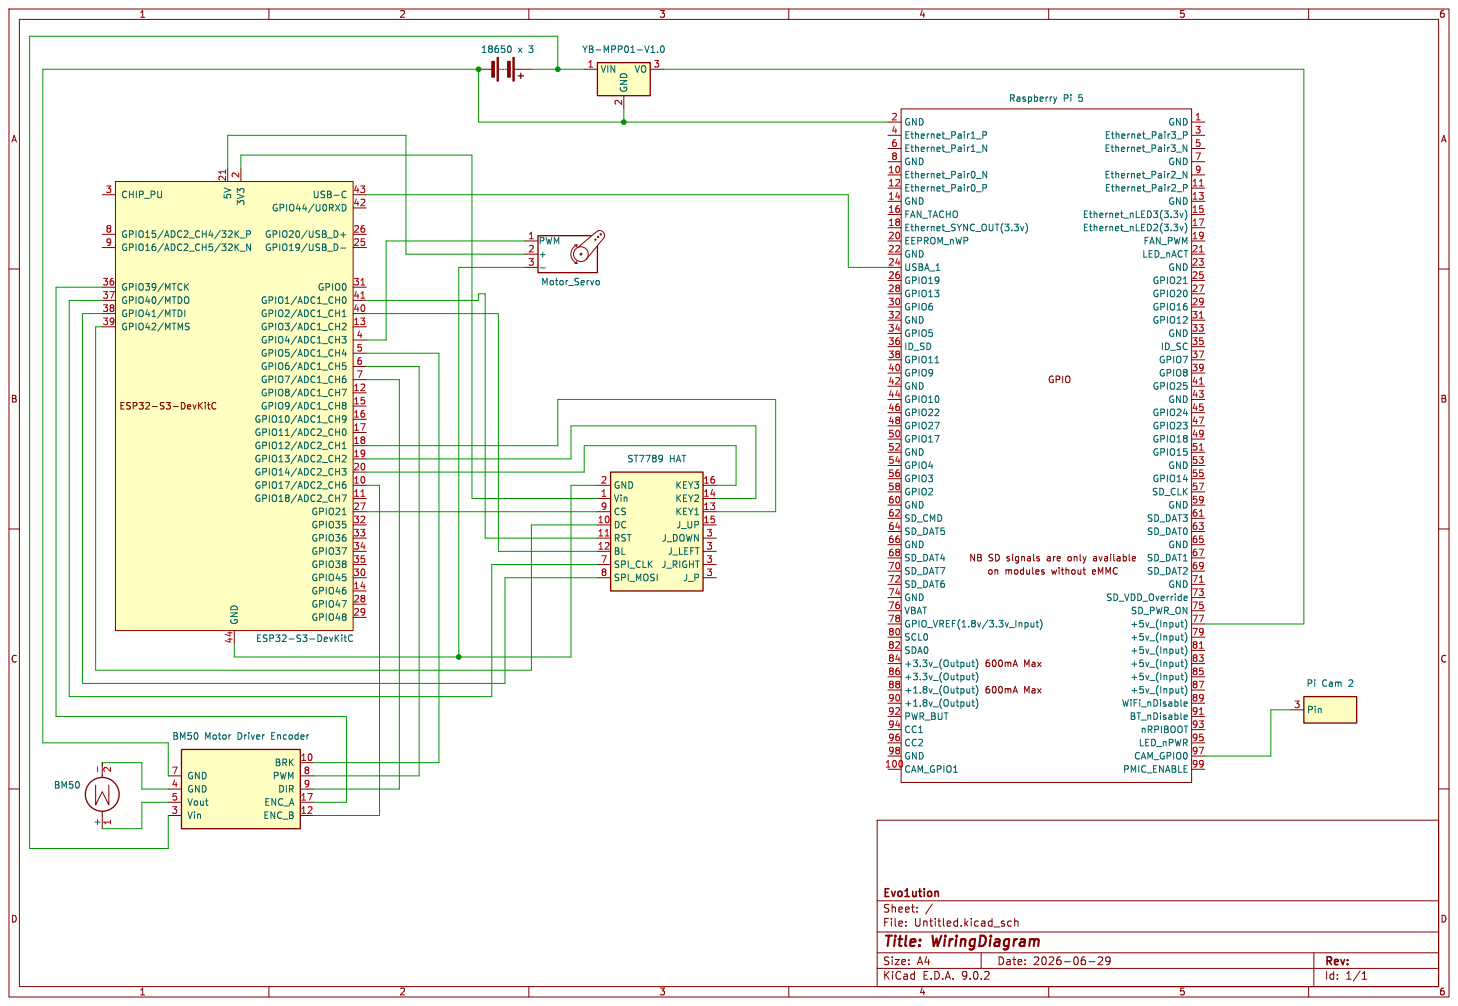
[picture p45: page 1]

ID_SD 36 GPIO11 38 GPIO9 40 GND 42 GPIO10 44 GPIO22 46 GPIO27 48 GPIO17 50 GND 52 GPIO4 54 GPIO3 56 GPIO2 58 GND 60 SD_CMD 62 SD_DAT5 64 GND 66 SD_DAT4 68 SD_DAT7 70 SD_DAT6 72 GND 74 VBAT 76 GPIO_VREF(1.8v/3.3v_Input) 78 SCL0 80 SDA0 82 +3.3v_(Output) 84 +3.3v_(Output) 86 +1.8v_(Output) 88 +1.8v_(Output) 90 PWR_BUT 92 CC1 94 CC2 96 GND 98 CAM_GPIO1 100

GND 2 Ethernet_Pair1_P 4 Ethernet_Pair1_N 6 GND 8 Ethernet_Pair0_N 10 Ethernet_Pair0_P 12 GND 14 FAN_TACHO 16 Ethernet_SYNC_OUT(3.3v) 18 EEPROM_nWP 20 GND 22 USBA_1 24 GPIO19 26 GPIO13 28 GPIO6 30 GND 32 GPIO5 34

on modules without eMMC GPIO

600mA Max 600mA Max NB SD signals are only available

ENC_B 12 ENC_A 17 DIR 9 PWM 8 BRK 10 Vin 3 Vout 5 GND 4 GND 7BM50 Motor Driver Encoder

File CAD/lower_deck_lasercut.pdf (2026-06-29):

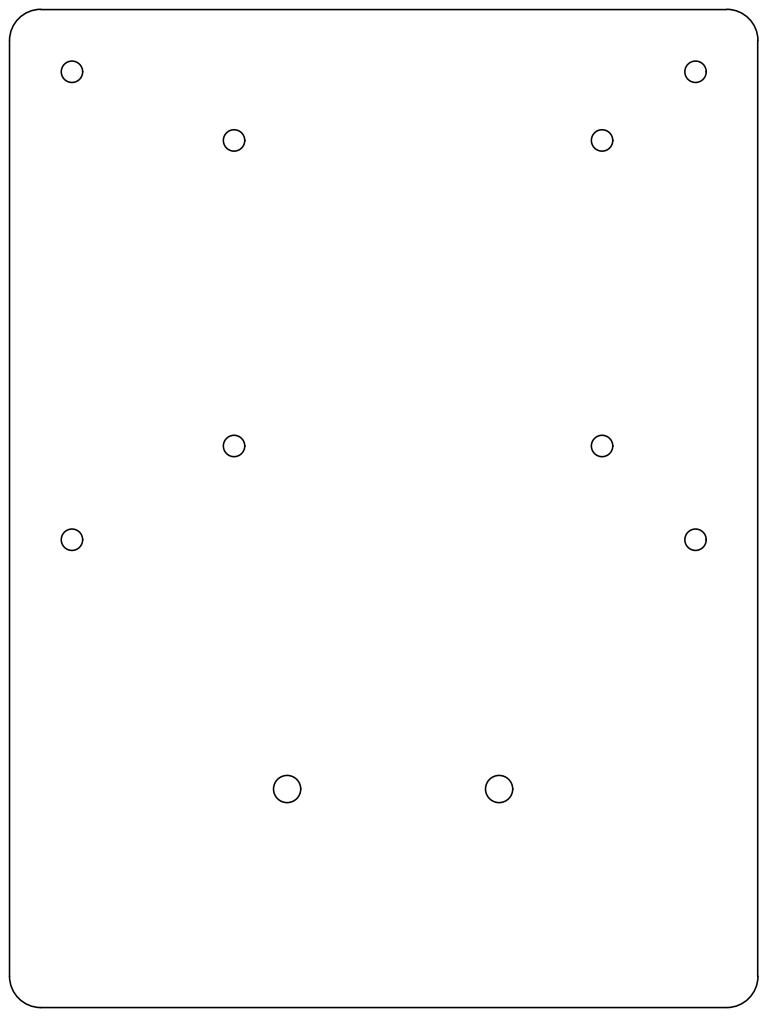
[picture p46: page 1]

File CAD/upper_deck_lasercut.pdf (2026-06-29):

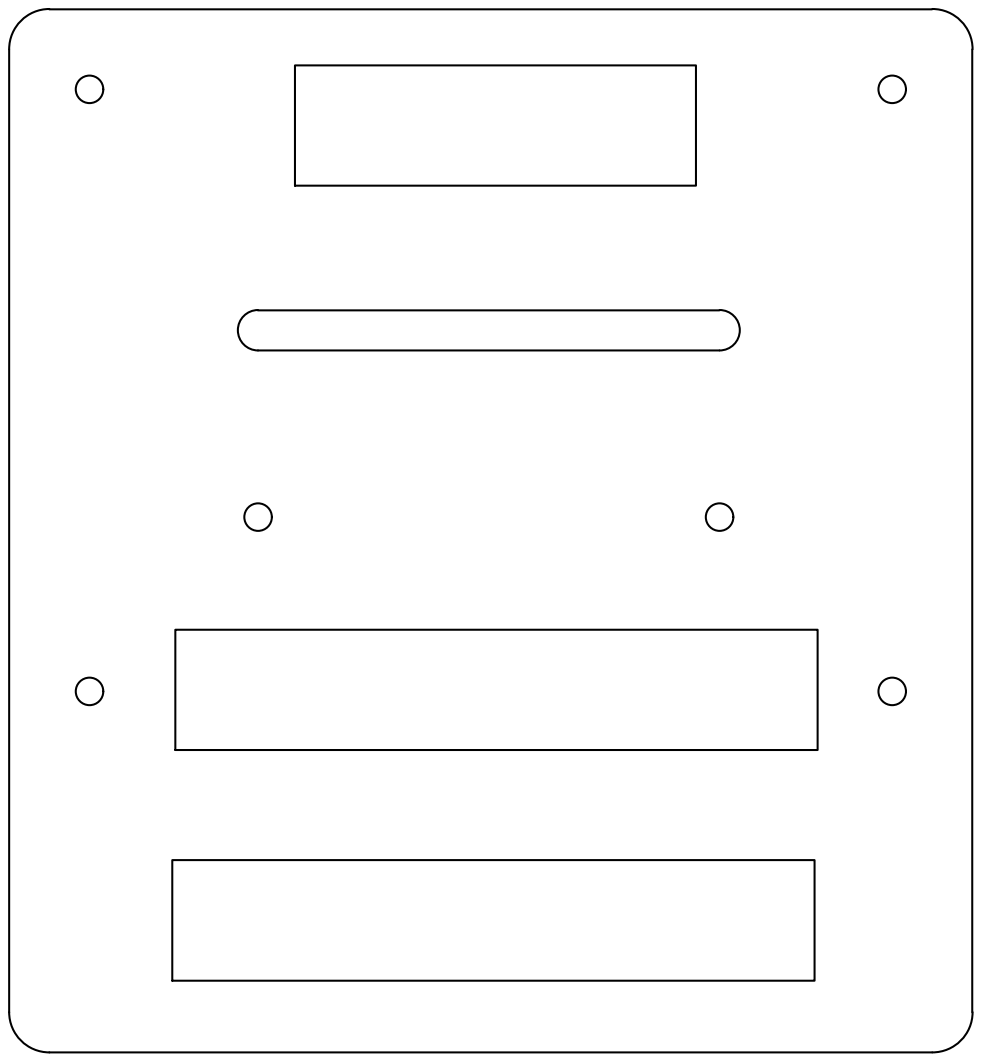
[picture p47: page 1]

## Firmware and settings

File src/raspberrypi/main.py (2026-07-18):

import cv2
import numpy as np
import time
import datetime
import math
from esp_com.communication import ESP32Communicator
from camera.camera_utils import start_vision_system, start_web_server, get_latest_data, stop_vision_system, get_track_distance, configure_vision_pipeline
from picamera2 import Picamera2 as picam2
from enum import Enum

# ESP communication and Picam init
print("======= Init =======")

esp = ESP32Communicator()
esp.connect()
camera = picam2()
video_size = (400, 225)
sensor_video_size = (2304, 1296)
target_frame_duration_us = 10000
config = camera.create_video_configuration(
	main={"size": video_size, "format": "BGR888"},
	sensor={"output_size": sensor_video_size},
	controls={"FrameDurationLimits": (target_frame_duration_us, target_frame_duration_us)},
	buffer_count=4,
	queue=False,
)
camera.configure(config)
camera.start()
print("Camera: Activated")

configure_vision_pipeline(
	draw_overlays=True,
	show_debug_strip=False,
	stream_use_debug_frame=False,
	record_use_debug_frame=False,
	stream_jpeg_quality=70,
)

start_vision_system(camera, True)

live_streaming = False
if live_streaming:
	print("Streaming: Activated")
	start_web_server(host='0.0.0.0', port=5000)
else:
	print("Streaming: Not streaming")

print("======= End of Init =======")

# Global variables
run_OC1 = False
run_OC2 = False
reset_OC = True
num_of_turn = 0
is_clockwise = True
start_time = 0
end_time = 0
recorded_time = 0

#Checkpoints (default as clockwise case)
angle = 0 #steering percentage
speed = 0
speed_var = 0
turn_flag = 0
turn_indi_1 = [200, 87.5] #check when to turn
turn_indi_2 = [200, 106.25] #check when to turn
sector_indi = [[150, 87.5], [250, 87.5]] #check when is sector
turn_time = 0
run_time = 0
lot_count = 0
lot_count_flag = 1
pillar_count = 0
pillar_count_flag = 1
pillar_count_temp = 0
enter_flag = 0
enter_flag_2 = 0
last_pillar_color = None
run_target_sent = False
target_done = False

front_turning_point = [200, 43.75]
left_turning_point = [25, 125] #check direction
right_turning_point = [375, 125] #check direction
turning_point = right_turning_point #check if the robot get to the position that should turn
track_left = [[50, 112.5], [325, 112.5]] #check if the robot is getting left from the ideal track
track_right = [[75, 112.5], [350, 112.5]] #check if the robot is getting right from the ideal track
ending_point = [200, 18.75] #check if the robot is at the ideal point to end

#States
class States(Enum):
	INIT = 0
	FIRST_SECTOR = 1 #Move forward until it knows the direction to run
	WAIT_TURN_STATE = 2 #Move forward for fixed distance to get to the ideal point to turn
	TURNING_STATE = 3 #Turn until it is parallel to the next path
	DASH_AFTER_TURNING_STATE = 4 #Move forward until it passed the corner sector
	RUN_SECTOR_STATE = 5 #Move forward until is time to turn
	LAST_RUN = 6 #Move forward to stop at the right place

class OC2_States(Enum):
	INIT = 0
	LEAVE = 1
	WHITE = 2
	PILLAR = 3
	ALIGN_0_0 = 4
	ALIGN_0_1 = 5
	ALIGN_1_0 = 6
	ALIGN_1_1 = 7
	STR_ENTER = 8
	ENTER = 9

# Function for receiving msg from ESP and print the message with timestamp
def esp_replyNprint():
	timestamp = datetime.datetime.now().strftime("%Y%m%d_%H%M%S")
	reply = esp.read_message()
	if reply is not None:
		timestamp = datetime.datetime.now().strftime("%Y%m%d_%H%M%S")
		print(f"{timestamp} ESP: {reply}")
	return reply

def send_command_logged(cmd):
	try:
		esp.send_command(cmd)
	except Exception as e:
		print(f"[SERIAL WRITE FAULT] Failed to transmit packet: {e}")

def clamp(value, minimum, maximum):
	return max(minimum, min(maximum, value))

def get_front_edge_angle(track_polygon, y_min=62, y_max=95):
	if track_polygon is None:
		return None

	pts = track_polygon.reshape(-1, 2)
	roi_pts = []
	for x, y in pts:
		if y_min <= y <= y_max:
			roi_pts.append([float(x), float(y)])

	if len(roi_pts) < 5:
		return None

	roi_pts = np.array(roi_pts, dtype=np.float32)
	vx, vy, _, _ = cv2.fitLine(roi_pts, cv2.DIST_L2, 0, 0.01, 0.01)
	angle_deg = math.degrees(math.atan2(float(vy), float(vx)))

	while angle_deg > 90:
		angle_deg -= 180
	while angle_deg < -90:
		angle_deg += 180
	return angle_deg

def wait_for_target_done(stop_reply="EOC2"):
	while True:
		reply = esp_replyNprint()
		if reply == stop_reply:
			return False
		if reply == "Done Target":
			return True
		time.sleep(0.001)

def run_parking_red():
	print("[PARKING] Using parking.py routine (last block RED)")
	PURPLE_TARGET_X = 293.75
	PURPLE_ALIGN_SPEED = 7.5
	PURPLE_STOP_THRESHOLD = 130
	PROBE_Y = 80.9375
	PROBE_LEFT_X = 162.5
	PROBE_RIGHT_X = 187.5
	STOP_DISTANCE_THRESHOLD = 0.625
	KP = 20
	KD = 1.2
	last_alignment_error = 0.0
	state = "ALIGNING"
	pause_start = 0.0

	while True:
		reply = esp_replyNprint()
		if reply == "EOC2":
			return False

		if state == "ALIGNING":
			_, parking, _ = get_latest_data()
			purple_x = parking.get("center_x", 0)
			purple_width = parking.get("width", 0)
			purple_height = parking.get("height", 0)
			purple_area = (purple_width * purple_height) // 100

			if purple_x != 0 and purple_area > 10:
				if purple_area >= PURPLE_STOP_THRESHOLD:
					send_command_logged("0, 0, 0, wall 1 stop")
					state = "WALL_1_PAUSE"
					pause_start = time.time()
				else:
					error = purple_x - PURPLE_TARGET_X
					align_steering = int(clamp(error * 1.9, -65, 65))
					send_command_logged(f"{PURPLE_ALIGN_SPEED}, {align_steering}, 0, purple align")
			else:
				send_command_logged("0, 0, 0, tracking lost holding")

		elif state == "WALL_1_PAUSE":
			if time.time() - pause_start < 1.5:
				send_command_logged("0, 0, 0, holding pause")
			else:
				state = "BLACK_WALL_PD_APPROACH"
				last_alignment_error = 0.0

		elif state == "BLACK_WALL_PD_APPROACH":
			_, dist_left = get_track_distance(PROBE_LEFT_X, PROBE_Y)
			_, dist_right = get_track_distance(PROBE_RIGHT_X, PROBE_Y)
			dist_left += 1.0625

			if dist_left < STOP_DISTANCE_THRESHOLD or dist_right < STOP_DISTANCE_THRESHOLD:
				send_command_logged("0, 0, 0, R")
				time.sleep(1.0)
				state = "BACKWARD"
				continue

			alignment_error = dist_left - dist_right
			derivative = alignment_error - last_alignment_error
			pd_steering = int(clamp((KP * alignment_error) + (KD * derivative), -55, 55))
			last_alignment_error = alignment_error
			send_command_logged(f"6, {pd_steering}, 0, pd front wall alignment")

		elif state == "BACKWARD":
			send_command_logged("-9, 0, 1, forward target")
			if not wait_for_target_done():
				return False
			send_command_logged("-1, 0, 0, R")
			state = "BACKWARD_TURN_1"

		elif state == "BACKWARD_TURN_1":
			steer = -100 if is_clockwise else 100
			send_command_logged(f"-9, {steer}, 45, forward target")
			if not wait_for_target_done():
				return False
			send_command_logged("-1, 0, 0, R")
			state = "BACKWARD_STRAIGHT"

		elif state == "BACKWARD_STRAIGHT":
			send_command_logged("-9, 0, 3, forward target")
			if not wait_for_target_done():
				return False
			send_command_logged("-1, 0, 0, R")
			state = "BACKWARD_TURN_2"

		elif state == "BACKWARD_TURN_2":
			steer = 100 if is_clockwise else -100
			send_command_logged(f"-9, {steer}, 55, forward target")
			if not wait_for_target_done():
				return False
			send_command_logged("-1, 0, 0, R")
			state = "COMPLETED"

		elif state == "COMPLETED":
			send_command_logged("0, 0, 0, parking complete")
			return True

		time.sleep(0.02)

def run_parking_other():
	print("[PARKING] Using parking2.py routine (last block not RED)")
	PROBE_Y_FORWARD = 83.75
	PROBE_LEFT_X_FORWARD = 200
	PROBE_RIGHT_X_FORWARD = 225
	TARGET_DIST = 0.625
	MIN_STOP_DIST = 0.5625
	MAX_STOP_DIST = 0.6875
	KP_SPEED = 10.0
	KP = 30
	KD = 1.2
	last_alignment_error = 0.0
	last_direction = None
	oscillation_count = 0
	state = "BLACK_WALL_PD_APPROACH"

	while True:
		reply = esp_replyNprint()
		if reply == "EOC2":
			return False

		if state == "BLACK_WALL_PD_APPROACH":
			_, dist_left = get_track_distance(PROBE_LEFT_X_FORWARD, PROBE_Y_FORWARD)
			_, dist_right = get_track_distance(PROBE_RIGHT_X_FORWARD, PROBE_Y_FORWARD)
			dist_left += 0.3125

			if (MIN_STOP_DIST <= dist_left <= MAX_STOP_DIST) and (MIN_STOP_DIST <= dist_right <= MAX_STOP_DIST):
				send_command_logged("0, 0, 0, R")
				state = "COMPLETED"
				continue

			mean_distance = (dist_left + dist_right) / 2.0
			dist_error = mean_distance - TARGET_DIST
			current_direction = 1 if dist_error >= 0 else -1
			if last_direction is not None and current_direction != last_direction:
				oscillation_count += 1
				if oscillation_count >= 2:
					send_command_logged("0, 0, 0, R")
					state = "COMPLETED"
					continue

			last_direction = current_direction
			base_speed = float(clamp(dist_error * KP_SPEED, -6.0, 6.0))
			speed_mode = "smooth forward approach" if base_speed >= 0 else "smooth overshoot backing"
			alignment_error = dist_left - dist_right
			derivative = alignment_error - last_alignment_error
			pd_steering = int(clamp((KP * alignment_error) + (KD * derivative), -55, 55))
			last_alignment_error = alignment_error
			if base_speed < 0:
				pd_steering = -pd_steering
			send_command_logged(f"{base_speed:.1f}, {pd_steering}, 0, {speed_mode}")

		elif state == "COMPLETED":
			state = "RIGHT_TURN_90"

		elif state == "RIGHT_TURN_90":
			send_command_logged("-8.5, 100, 61, forward target")
			if not wait_for_target_done():
				return False
			send_command_logged("0, 0, 0, R")
			state = "STEERING_REALIGN"

		elif state == "STEERING_REALIGN":
			send_command_logged("0, -30, 0, friction break pulse")
			time.sleep(0.15)
			send_command_logged("0, 0, 0, R")
			state = "BACKWARD_ENCODER_MOVE"

		elif state == "BACKWARD_ENCODER_MOVE":
			send_command_logged("-8.5, 0, 72, forward target")
			if not wait_for_target_done():
				return False
			send_command_logged("0, 0, 0, R")
			state = "FINAL_TURN_90"

		elif state == "FINAL_TURN_90":
			send_command_logged("8.5, 100, 45, forward target")
			if not wait_for_target_done():
				return False
			send_command_logged("0, -30, 0, friction break pulse")
			time.sleep(0.15)
			send_command_logged("0, 0, 0, R")
			state = "REAR_SAFETY_BACKOFF"

		elif state == "REAR_SAFETY_BACKOFF":
			send_command_logged("-8.5, -30, 16, forward target")
			if not wait_for_target_done():
				return False
			send_command_logged("0, 0, 0, R")
			state = "FINAL_CORRECTION_TURN"

		elif state == "FINAL_CORRECTION_TURN":
			send_command_logged("-8.5, -100, 47, forward target")
			if not wait_for_target_done():
				return False
			send_command_logged("0, 60, 0, dynamic shake right")
			time.sleep(0.18)
			send_command_logged("0, 0, 0, straight hold")
			time.sleep(0.10)
			send_command_logged("0, 0, 0, R")
			return True

		time.sleep(0.02)

def run_parking_align_0_0_enter():
	print("[PARKING] Using standalone parking.py routine from ALIGN_0_0 -> ENTER")
	PURPLE_TARGET_X = 290
	PURPLE_ALIGN_SPEED = 5
	PURPLE_STOP_THRESHOLD = 61.5
	PROBE_Y = 71
	PROBE_LEFT_X = 179
	PROBE_RIGHT_X = 204
	STOP_DISTANCE_THRESHOLD = 1.0
	KP = 16
	KD = 1.2
	last_alignment_error = 0.0
	target_done = False
	run_target_sent = False
	state = "ALIGNING"
	pause_start = 0.0

	while True:
		reply = esp_replyNprint()
		if reply == "EOC2":
			return False
		if reply == "Done Target":
			target_done = True

		if state == "ALIGNING":
			_, parking, _ = get_latest_data()
			purple_x = parking.get("center_x", 0)
			purple_area = (parking.get("width", 0) * parking.get("height", 0)) // 100

			print(f"[TRACKING WALL 1] X: {purple_x} | Area: {purple_area}")

			if purple_x != 0 and purple_area > 10:
				if purple_area >= PURPLE_STOP_THRESHOLD:
					print("[WALL 1 DETECTED] Halting for temporary pause...")
					send_command_logged("0, 0, 0, wall 1 stop")
					state = "WALL_1_PAUSE"
					pause_start = time.time()
				else:
					error = purple_x - PURPLE_TARGET_X
					align_steering = int(clamp(error * 1.9, -55, 55))
					send_command_logged(f"{PURPLE_ALIGN_SPEED}, {align_steering}, 0, purple align")
			else:
				send_command_logged("0, 0, 0, tracking lost holding")

		elif state == "WALL_1_PAUSE":
			if time.time() - pause_start < 1.5:
				send_command_logged("0, 0, 0, holding pause")
			else:
				print("[SYSTEM] Pause complete. Transitioning to Continuous PD Wall Approach...")
				state = "BLACK_WALL_PD_APPROACH"
				last_alignment_error = 0.0

		elif state == "BLACK_WALL_PD_APPROACH":
			_, parking, track = get_latest_data()
			purple_y = parking.get("center_y", 0)
			touch_inside, touch_dist = get_track_distance(150, 77)
			print(f"[TOUCH POINT (150, 77)] Inside Poly: {int(touch_inside)} | Distance to Edge: {touch_dist:.2f}")
			print(f"[PARKING LOT Y] {purple_y}")

			if touch_dist < STOP_DISTANCE_THRESHOLD:
				send_command_logged("0, 0, 0, R")
				print(f"[WALL ARRIVAL MET] Edge distance dropped below {STOP_DISTANCE_THRESHOLD}")
				time.sleep(1.0)
				state = "BACKWARD"
				run_target_sent = False
				target_done = False
				continue

			if purple_y > 180:
				edge_angle = get_front_edge_angle(track.get("polygon"))
				if edge_angle is not None:
					print(f"[FRONT EDGE ANGLE] {edge_angle:+.2f} deg")
					alignment_error = edge_angle
					derivative = alignment_error - last_alignment_error
					pd_steering = int(clamp(-(2.8 * alignment_error) - (0.9 * derivative) - 12, -55, 55))
					last_alignment_error = alignment_error
					send_command_logged(f"{PURPLE_ALIGN_SPEED}, {pd_steering}, 0, front edge line align")
					print(f"[PD CONTROL] Edge Angle Error: {alignment_error:+.2f} deg | Transmitted Steer: {pd_steering}")
				else:
					has_poly_l, dist_left = get_track_distance(PROBE_LEFT_X, PROBE_Y)
					has_poly_r, dist_right = get_track_distance(PROBE_RIGHT_X, PROBE_Y)
					if dist_left is None or dist_right is None:
						send_command_logged(f"{PURPLE_ALIGN_SPEED}, 0, 0, fallback probe search")
					else:
						dist_left += 0.6
						print(f"[FALLBACK PROBE LEFT  ({PROBE_LEFT_X}, {PROBE_Y})] Inside Poly: {int(has_poly_l)} | Distance to Edge: {dist_left:.2f}")
						print(f"[FALLBACK PROBE RIGHT ({PROBE_RIGHT_X}, {PROBE_Y})] Inside Poly: {int(has_poly_r)} | Distance to Edge: {dist_right:.2f}")
						alignment_error = dist_left - dist_right
						derivative = alignment_error - last_alignment_error
						pd_steering = int(clamp((KP * alignment_error) + (KD * derivative), -55, 55))
						last_alignment_error = alignment_error
						send_command_logged(f"{PURPLE_ALIGN_SPEED}, {pd_steering}, 0, fallback probe align")
			else:
				has_poly_l, dist_left = get_track_distance(PROBE_LEFT_X, PROBE_Y)
				has_poly_r, dist_right = get_track_distance(PROBE_RIGHT_X, PROBE_Y)
				if dist_left is None or dist_right is None:
					send_command_logged(f"{PURPLE_ALIGN_SPEED}, 0, 0, fallback probe search")
				else:
					dist_left += 0.6
					print(f"[FALLBACK PROBE LEFT  ({PROBE_LEFT_X}, {PROBE_Y})] Inside Poly: {int(has_poly_l)} | Distance to Edge: {dist_left:.2f}")
					print(f"[FALLBACK PROBE RIGHT ({PROBE_RIGHT_X}, {PROBE_Y})] Inside Poly: {int(has_poly_r)} | Distance to Edge: {dist_right:.2f}")
					alignment_error = dist_left - dist_right
					derivative = alignment_error - last_alignment_error
					pd_steering = int(clamp((KP * alignment_error) + (KD * derivative), -55, 55))
					last_alignment_error = alignment_error
					send_command_logged(f"{PURPLE_ALIGN_SPEED}, {pd_steering}, 0, fallback probe align")

		elif state == "BACKWARD":
			if run_target_sent == False:
				send_command_logged("-6, 0, 1, forward target")
				run_target_sent = True
				target_done = False
			if not target_done:
				time.sleep(0.001)
				continue
			send_command_logged("-1, 0, 0, R")
			state = "BACKWARD_TURN_1"
			run_target_sent = False
			target_done = False
			continue

		elif state == "BACKWARD_TURN_1":
			if run_target_sent == False:
				send_command_logged("6, -100, 43, P")
				run_target_sent = True
				target_done = False
			if not target_done:
				time.sleep(0.001)
				continue
			send_command_logged("0, 60, 0, R")
			state = "BACKWARD_TURN_1A"
			run_target_sent = False
			target_done = False
			continue

		elif state == "BACKWARD_TURN_1A":
			if run_target_sent == False:
				send_command_logged("-6, 30, 30, P")
				run_target_sent = True
				target_done = False
			if not target_done:
				time.sleep(0.001)
				continue
			send_command_logged("-1, 0, 0, R")
			state = "BACKWARD_TURN_2"
			run_target_sent = False
			target_done = False
			continue

		elif state == "BACKWARD_TURN_2":
			if run_target_sent == False:
				send_command_logged("0, 0, -1, stop")
				send_command_logged("-6, -100, 33, P")
				run_target_sent = True
				target_done = False
			if not target_done:
				time.sleep(0.001)
				continue
			send_command_logged("0, 0, 0, R")
			state = "STRAIGHT"
			run_target_sent = False
			target_done = False
			continue

		elif state == "STRAIGHT":
			if run_target_sent == False:
				send_command_logged("6, 100, 7, forward target")
				run_target_sent = True
				target_done = False
			if not target_done:
				time.sleep(0.001)
				continue
			send_command_logged("0, -60, 0, R")
			state = "COMPLETED"
			run_target_sent = False
			target_done = False
			continue

		elif state == "COMPLETED":
			send_command_logged("0, 0, 0, parking complete")
			return True

		time.sleep(0.02)
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

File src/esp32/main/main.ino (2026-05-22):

#include "main.h"

// Create threads for different tasks
TaskHandle_t blinkledThread = NULL;
TaskHandle_t displayThread = NULL;
TaskHandle_t OCThread = NULL;
TaskHandle_t SteeringThread = NULL;
TaskHandle_t MotorEncThread = NULL;

void setup() {
  // Initialization
  motor_preinit_safe();
  Serial.begin(115200);
  tft.init();
  tft.displayln(30, 0, 2, "Initializing...", TFT_WHITE, true);
  
  // Showing the init status of each components
  int line_iter = 2;
  #ifdef FENZY_MODE
    tft.displayLeftln(line_iter++, 2, "LED Init:", TFT_WHITE, false);
    tft.displayLeftln(line_iter++, 2, "Clk Init:", TFT_WHITE, false);
    tft.displayLeftln(line_iter++, 2, "Srl Init:", TFT_WHITE, false);
    tft.displayLeftln(line_iter++, 2, "Btn Init:", TFT_WHITE, false);
    tft.displayLeftln(line_iter++, 2, "Str Init:", TFT_WHITE, false);
    tft.displayLeftln(line_iter++, 2, "Mtr Init:", TFT_WHITE, false);
  #endif

  Serial.println("ESP_INIT");
  
  line_iter = 2;
  led_init();
  #ifdef FENZY_MODE
    delay(100);
    tft.displayRightln(line_iter++, 2, "Done", TFT_GREEN, false);
  #endif

  internalClock.start();
  #ifdef FENZY_MODE
    delay(100);
    tft.displayRightln(line_iter++, 2, "Done", TFT_GREEN, false);
  #endif

  Serial.begin(115200);
  #ifdef FENZY_MODE
    delay(100);
    tft.displayRightln(line_iter++, 2, "Done", TFT_GREEN, false);
  #endif

  btn_init();
  #ifdef FENZY_MODE
    delay(100);
    tft.displayRightln(line_iter++, 2, "Done", TFT_GREEN, false);
  #endif

  steeringInit();
  #ifdef FENZY_MODE
    delay(100);
    tft.displayRightln(line_iter++, 2, "Done", TFT_GREEN, false);
  #endif

  motor_init();
  #ifdef FENZY_MODE
    delay(100);
    tft.displayRightln(line_iter++, 2, "Done", TFT_GREEN, false);
  #endif


  xTaskCreatePinnedToCore(
    blinkledLED_test,         // Task function
    "Blink LED",              // Task name
    10000,                    // Stack size (bytes)
    NULL,                     // Parameters
    1,                        // Priority
    &blinkledThread,          // Task handle
    1                         // Core 1
  );

  xTaskCreatePinnedToCore(
    steeringloop,             // Task function
    "Steering",               // Task name
    10000,                    // Stack size (bytes)
    NULL,                     // Parameters
    1,                        // Priority
    &SteeringThread,          // Task handle
    0                         // Core 0
  );

  xTaskCreatePinnedToCore(
    motor_encloop,            // Task function
    "Motor Encoder",          // Task name
    10000,                    // Stack size (bytes)
    NULL,                     // Parameters
    1,                        // Priority
    &MotorEncThread,          // Task handle
    0                         // Core 0
  );

  #ifdef FENZY_MODE
    delay(500);
  #else
    delay(300);
  #endif

  tft.clear();

  xTaskCreatePinnedToCore(
    displayData,              // Task function
    "Display info",           // Task name
    10000,                    // Stack size (bytes)
    NULL,                     // Parameters
    1,                        // Priority
    &displayThread,           // Task handle
    1                         // Core 1
  );

  Serial.println("ESP_IDLE");

  xTaskCreatePinnedToCore(
    OCmain,                  // Task function
    "OC",                    // Task name
    10000,                    // Stack size (bytes)
    NULL,                     // Parameters
    1,                        // Priority
    &OCThread,               // Task handle
    0                         // Core 0
  );
}

void loop() {
  // Nothing as the threads handle everything
}

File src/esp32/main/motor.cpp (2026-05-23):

#include "HardwareSerial.h"
#include "Motor.h"
#include "motor.h"
#include <math.h>
#include <driver/pulse_cnt.h> 

// Global variables for the BM50 motor
volatile long MOTOR_ENCODER_COUNT = 0;
long          MOTOR_ENCODER_VALUE = 0;

// PWM polarity (true = active-low)
const bool PWM_ACTIVE_LOW = true;

static pcnt_unit_handle_t    s_pcnt_unit = nullptr;
static pcnt_channel_handle_t s_chan_a    = nullptr;
static pcnt_channel_handle_t s_chan_b    = nullptr;

/**
 * @brief Helper functions to convert percentage to duty cycle
 * @param p; int; percentage
 */
static inline uint32_t duty_from_percent(int p) {
  int mag = abs(p);
  if (mag > 100) mag = 100;
  uint32_t d = (uint32_t)mag * PWM_MAX_DUTY / 100;
  if (PWM_ACTIVE_LOW) d = PWM_MAX_DUTY - d;
  return d;
}

/**
 * @brief Helper functions to apply motor direction to pwm
 * @param p; int; motor direction
 */
static inline void apply_pwm_dir(int p) {
  digitalWrite(PIN_M_DIR, (p >= 0) ? HIGH : LOW);
  digitalWrite(PIN_M_BRAKE, HIGH);                      // release brake
  ledcWrite(PIN_M_PWM, duty_from_percent(p));
}

/**
 * @brief PCNT encoder setup function
 */
static void encoder_pcnt_init() {
  pcnt_unit_config_t unit_cfg = {};
  unit_cfg.low_limit  = INT16_MIN;
  unit_cfg.high_limit = INT16_MAX;
  ESP_ERROR_CHECK(pcnt_new_unit(&unit_cfg, &s_pcnt_unit));

  // Glitch filter to suppress EMI/bounce (tune 200..2000 ns)
  pcnt_glitch_filter_config_t filt_cfg = {};
  filt_cfg.max_glitch_ns = 1000;
  ESP_ERROR_CHECK(pcnt_unit_set_glitch_filter(s_pcnt_unit, &filt_cfg));

  // Channel A: edge=A, level=B
  pcnt_chan_config_t ch_a_cfg = {};
  ch_a_cfg.edge_gpio_num  = PIN_ENC_A;
  ch_a_cfg.level_gpio_num = PIN_ENC_B;
  ESP_ERROR_CHECK(pcnt_new_channel(s_pcnt_unit, &ch_a_cfg, &s_chan_a));

  // Channel B: edge=B, level=A
  pcnt_chan_config_t ch_b_cfg = {};
  ch_b_cfg.edge_gpio_num  = PIN_ENC_B;
  ch_b_cfg.level_gpio_num = PIN_ENC_A;
  ESP_ERROR_CHECK(pcnt_new_channel(s_pcnt_unit, &ch_b_cfg, &s_chan_b));

  // Quadrature actions (standard mapping)
  ESP_ERROR_CHECK(pcnt_channel_set_edge_action(
    s_chan_a, PCNT_CHANNEL_EDGE_ACTION_INCREASE, PCNT_CHANNEL_EDGE_ACTION_DECREASE));
  ESP_ERROR_CHECK(pcnt_channel_set_level_action(
    s_chan_a, PCNT_CHANNEL_LEVEL_ACTION_KEEP, PCNT_CHANNEL_LEVEL_ACTION_INVERSE));

  ESP_ERROR_CHECK(pcnt_channel_set_edge_action(
    s_chan_b, PCNT_CHANNEL_EDGE_ACTION_INCREASE, PCNT_CHANNEL_EDGE_ACTION_DECREASE));
  ESP_ERROR_CHECK(pcnt_channel_set_level_action(
    s_chan_b, PCNT_CHANNEL_LEVEL_ACTION_INVERSE, PCNT_CHANNEL_LEVEL_ACTION_KEEP));

  ESP_ERROR_CHECK(pcnt_unit_enable(s_pcnt_unit));
  ESP_ERROR_CHECK(pcnt_unit_clear_count(s_pcnt_unit));
  ESP_ERROR_CHECK(pcnt_unit_start(s_pcnt_unit));
}

/**
 * @brief Init function for the motor
 */
void motor_init() {
  // Keep brake asserted until PWM ready
  digitalWrite(PIN_M_BRAKE, LOW);

  ledcAttach(PIN_M_PWM, PWM_FREQ_HZ, PWM_BITS);
  ledcWrite(PIN_M_PWM, PWM_ACTIVE_LOW ? PWM_MAX_DUTY : 0); // OFF

  pinMode(PIN_M_DIR, OUTPUT);
  digitalWrite(PIN_M_DIR, LOW);

  pinMode(PIN_M_BRAKE, OUTPUT);

  // Encoder pins & PCNT
  pinMode(PIN_ENC_A, INPUT_PULLUP);
  pinMode(PIN_ENC_B, INPUT_PULLUP);
  encoder_pcnt_init();

  MOTOR_ENCODER_COUNT = 0;
  MOTOR_ENCODER_VALUE = 0;
}

/**
 * @brief Read the encoder value from the encoder sensor to update the global variable
 */
void read_encoder() {
  int hw = 0;
  if (s_pcnt_unit) pcnt_unit_get_count(s_pcnt_unit, &hw);
  MOTOR_ENCODER_COUNT = (long)hw;
  MOTOR_ENCODER_VALUE = (long)hw;
}

/**
 * @brief Reset the encoder value 
 */
void reset_encoder() {
  if (s_pcnt_unit) pcnt_unit_clear_count(s_pcnt_unit);
  MOTOR_ENCODER_COUNT = 0;
  MOTOR_ENCODER_VALUE = 0;
}

/**
 * @brief Move the motor with the input power
 * @param speed_percentage; int; Speed percentage (-100% ~ 100%) (Negative as moving backward)
 */
void motor_move(int speed_percentage) {
  if (speed_percentage > 100)  speed_percentage = 100;
  if (speed_percentage < -100) speed_percentage = -100;
  apply_pwm_dir(-speed_percentage);
}

/**
 * @brief Stop the motor with the input method
 * @param brake_method; BRAKE_TYPE; Method to brake the motor. BRAKE: stop the motor by providing a force to it. COAST: stop the motor by without providing
 * an external force
 */
void motor_stop(BRAKE_TYPE brake_method) {
  // PWM off
  ledcWrite(PIN_M_PWM, PWM_ACTIVE_LOW ? PWM_MAX_DUTY : 0);
  if (brake_method == BRAKE) digitalWrite(PIN_M_BRAKE, LOW);   // active brake
  else                       digitalWrite(PIN_M_BRAKE, HIGH);  // coast
}

/**
 * @brief Blocking move by degrees (sign of deg = direction)
 * @param deg; int; encoder value to be moved
 * @param speed_percentage; int; Speed percentage (-100% ~ 100%) (Negative as moving backward)
 * @param brake_method; BRAKE_TYPE; Method to brake the motor. BRAKE: stop the motor by providing a force to it. COAST: stop the motor by without providing
 */
void motor_on_degree(int deg, int speed_percentage, BRAKE_TYPE brake_method) {
  if (deg == 0 || speed_percentage == 0) { motor_stop(brake_method); return; }

  // target ticks (abs)
  long target_ticks = (long)(( (double)ENCODER_CPR * (double)abs(deg) ) / 360.0);
  if (target_ticks == 0) target_ticks = 1;

  // start reference
  read_encoder();
  long start = MOTOR_ENCODER_VALUE;

  // direction from sign of deg
  int dir = (deg >= 0) ? 1 : -1;
  motor_move(dir * abs(speed_percentage));

  const uint32_t timeout_ms = 10000; // safety
  uint32_t t0 = millis();
  for (;;) {
    read_encoder();
    long progressed = labs(MOTOR_ENCODER_VALUE - start);
    if (progressed >= target_ticks) break;
    if ((uint32_t)(millis() - t0) > timeout_ms) break;
    vTaskDelay(pdMS_TO_TICKS(2));
  }

  motor_stop(brake_method);
}
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

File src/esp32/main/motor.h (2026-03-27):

#pragma once
#include <Arduino.h>
#include <Ticker.h>
#include <math.h>
#include "tft.h"

// Pins of the motor and encoder connected
#define PIN_M_BRAKE   5    // LOW = brake, HIGH = run
#define PIN_M_PWM     6    // LEDC PWM pin
#define PIN_M_DIR     7    // DIR pin
#define PIN_ENC_A     39   // encoder A
#define PIN_ENC_B     17   // encoder B

// Encoder setting
#ifndef ENCODER_CPR
#define ENCODER_CPR   600   // counts per mechanical revolution
#endif

// PWM setting
#define PWM_FREQ_HZ   20000     // 20 kHz
#define PWM_BITS      8
#define PWM_MAX_DUTY  ((1u << PWM_BITS) - 1)
extern const bool PWM_ACTIVE_LOW;   // defined in motor.cpp

// Encoder value from the distance travelled by the car
#define ENC_PER_CM 1.44

// Stop modes for the motor
typedef enum{
  COAST = 0, 
  BRAKE = 1 
} BRAKE_TYPE;

// Global variables storing the motor encoder value
extern volatile long MOTOR_ENCODER_COUNT;   // live value (PCNT reading)
extern long          MOTOR_ENCODER_VALUE;   // last snapshotted value by read_encoder()

// Safe preinit function for the motor
static inline void motor_preinit_safe() {
  pinMode(PIN_M_BRAKE, OUTPUT);
  digitalWrite(PIN_M_BRAKE, LOW);                               // assert brake

  pinMode(PIN_M_PWM, OUTPUT);
  digitalWrite(PIN_M_PWM, /*OFF*/ PWM_ACTIVE_LOW ? HIGH : LOW); // force PWM OFF level

  pinMode(PIN_M_DIR, OUTPUT);
  digitalWrite(PIN_M_DIR, LOW);
}

void motor_init();                              
void read_encoder();                            
void reset_encoder();                           
void motor_move(int speed_percentage);          
void motor_stop(BRAKE_TYPE brake_method);       
void motor_on_degree(int deg, int speed_percentage, BRAKE_TYPE brake_method);
bool motor_degree_accel(float dist, float accel_dist, float decel_dist, float init_speed, float max_speed);
void motor_encloop(void* parameters);
void showEncoder(TFT_COLUMN column, int line_number, int text_size, uint16_t text_colour, bool clearDisplay);

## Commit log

2026-03-28 Testting new communitcation with esp32
2026-04-30 Minor mistake in the main.py
    [main.py]
2026-05-03 The framework of the OC1 function for raspberrypi is almost done, comments will be added later
2026-05-04 The function for raspberrypi to decide and send the state command to ESP32 is done
2026-05-05 The function for raspberrypi to identify states is updated
2026-05-10 Fix minor bugs and formatting
    [main.py]
2026-05-23 Finished ESP32 functions
2026-05-23 23/05 main.py error fixing
    [main.py]
2026-06-02 New OC1 strategy by tracking white track center
2026-06-09 Fact check the camera fov
2026-06-16 adding counter-steering pulse for OC2 (dodging pillar)
2026-06-17 Rex's stragegy (Stable for anti-clockwise, unstable for clockwise for unknown reason)
    [camera_utils.py]
2026-06-29 Solve: Low FPS and camera lock up when stopping OCs
2026-06-29 Fix: Capture once per loop, process once, no always-on duplicate worker threads unless proven needed.
    [camera_utils.py]
2026-06-29 Added wiring diagram and BOM
    [BOM.csv, gen1.kicad_sch, gen1_wiring.kicad_sch]
2026-06-29 Renaming files and folders
    [3dp_left_frame.stl, 3dp_right_frame.stl, BOM.csv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]
2026-07-02 Edit camera utils for better FPS
2026-07-02 Match camera_utils test camera mode to main
2026-07-02 Scale debug strip to frame width
2026-07-02 Fix recorded video frame format and size
    [camera_utils.py]
2026-07-02 Restore RGB camera color path
2026-07-02 Match Gen-1.0 camera color format
2026-07-02 Motor will stop now after OC1
2026-07-07 updated colour filter (red pillar sometimes recognise at both red & magenta)
2026-07-07 Testing camera utils filters
2026-07-09 Testing encoder for parking
2026-07-09 Revise team photos and design details in README
    Updated team photos and improved descriptions of the current design.
2026-07-10 Fix the racing issue in parking
    [OC.cpp, steering.cpp]
2026-07-11 red filter impro, spd & stear impro
2026-07-13 Port fast camera config to Gen-1.0
2026-07-13 Align Gen-1.0 camera filters with fast pipeline
2026-07-13 Finished patching upgrading camera lib to this branch
2026-07-13 Match parking camera setup to Gen-1.0
2026-07-13 Using white track edge for parking2.py
2026-07-14 out park with encoder
2026-07-14 handling dif parking case
2026-07-14 Edited camera_utils to ignore passed block
2026-07-14 anti cl case 1 parking done
2026-07-16 all align case written
